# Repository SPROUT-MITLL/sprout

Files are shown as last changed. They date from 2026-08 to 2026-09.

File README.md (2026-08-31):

# SPROUT

Main repository for SPROUT: an open-source, open-hardware soft robot for search and rescue.

📖 **Full documentation, CAD, electronics, and software guides: [sprout-mitll.github.io/sprout](https://sprout-mitll.github.io/sprout/)**

## Repository layout

- [`SPROUT_Design/CAD`](SPROUT_Design/CAD) — SolidWorks/STEP mechanical design files
- [`SPROUT_Design/Code`](SPROUT_Design/Code) — Jetson bootstrap guide and the `sprout_ros` ROS 2 stack
- [`SPROUT_Design/Documentation`](SPROUT_Design/Documentation) — supporting photos and the raw BOM spreadsheet for the [Documentation](https://sprout-mitll.github.io/sprout/documentation/) section of the site
- [`SPROUT_Design/Electronics`](SPROUT_Design/Electronics) — custom Arduino shield KiCad project
- [`docs/`](docs) — source for the GitHub Pages documentation site above

## License

Released under the [MIT License](LICENSE).

## Distribution Statement

DISTRIBUTION STATEMENT A. Approved for public release. Distribution is unlimited.
This material is based upon work supported by the Department of the Air Force under Air Force Contract No. FA8702-15-D-0001 or FA8702-25-D-B002. Any opinions, findings, conclusions or recommendations expressed in this material are those of the author(s) and do not necessarily reflect the views of the Department of the Air Force.
© 2026 Massachusetts Institute of Technology.

Subject to FAR52.227-11 Patent Rights - Ownership by the contractor (May 2014)
Delivered to the U.S. Government with Unlimited Rights, as defined in DFARS Part 252.227-7013 or 7014 (Feb 2014). Notwithstanding any copyright notice, U.S. Government rights in this work are defined by DFARS 252.227-7013 or DFARS 252.227-7014 as detailed above. Use of this work other than as specifically authorized by the U.S. Government may violate any copyrights that exist in this work.

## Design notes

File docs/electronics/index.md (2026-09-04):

---
layout: default
title: Electronics
nav_order: 4
has_children: true
permalink: /electronics/
---

# Electronics
{: .no_toc }

Source: [`SPROUT_Design/Electronics`]({{ site.github_tree }}/SPROUT_Design/Electronics)
{: .label .label-green }

The `Electronics` directory contains the custom Arduino shield PCB that
interfaces the Arduino Uno Rev3 with the motor driver, QB3 pressure
regulators, solenoid valve, LCD screen, and the compute box's power rails (see
[Wiring]({{ site.baseurl }}/documentation/wiring.html) for the full pinout).

## Table of contents
{: .no_toc .text-delta }

- TOC
{:toc}

---

## Arduino shield

Source: [`Electronics/Arduino Shield`]({{ site.github_tree }}/SPROUT_Design/Electronics/Arduino%20Shield)
{: .label .label-green }

Designed in KiCad. The project targets an Arduino Uno Rev3 shield footprint
and breaks out the following interfaces referenced throughout the
[wiring guide]({{ site.baseurl }}/documentation/wiring.html):

- Motor driver power and control (`M_DRV_PWR`, `M_DRV_ARD`, `M_5V`)
- Solenoid valve output
- 15 V actuator/regulator rails (`M_15V`, `R_15V`)
- QB3 pressure regulator channels (Chamber, Actuator 1–3)
- I²C breakout for the LCD display

### 3D preview

{% assign step_url = site.github_raw | append: "/SPROUT_Design/Electronics/Arduino Shield/vine_robot_arduino_shield.step" %}
{% include step_viewer.html url=step_url name="Arduino shield" %}

<script type="module" src="{{ site.baseurl }}/assets/js/step-viewer.js"></script>

### Board layout

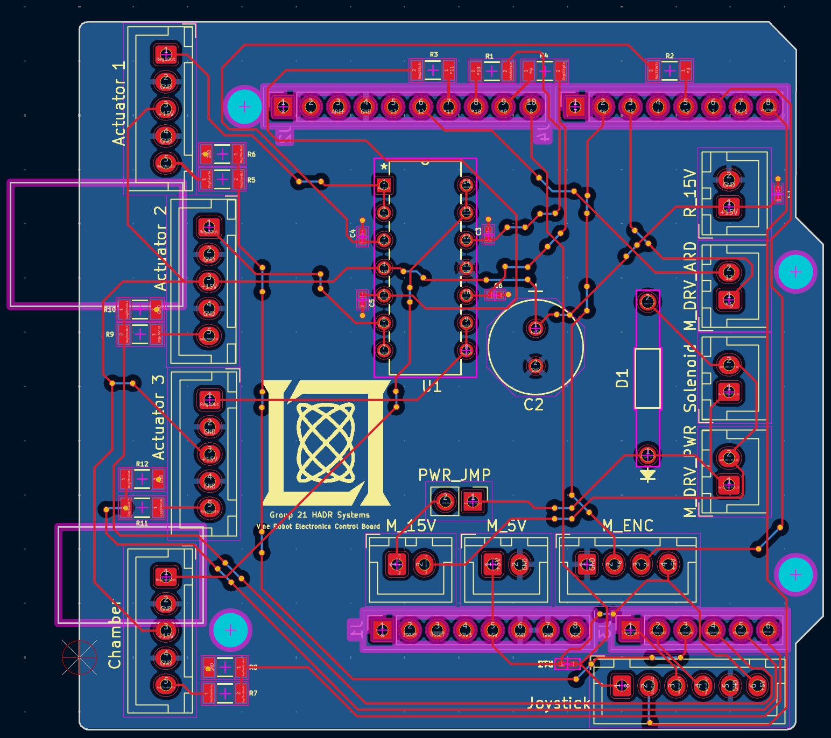
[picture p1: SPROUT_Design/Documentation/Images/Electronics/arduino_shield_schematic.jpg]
Arduino shield PCB layout


*Figure 1. PCB layout showing traces and connector pinouts for the actuator, solenoid, motor driver, power, encoder, and joystick headers referenced in the [wiring guide]({{ site.baseurl }}/documentation/wiring.html).*

| File | Description |
|---|---|
| [`vine_robot_arduino_shield.kicad_sch`]({{ site.github_blob }}/SPROUT_Design/Electronics/Arduino%20Shield/vine_robot_arduino_shield.kicad_sch) | KiCad schematic |
| [`vine_robot_arduino_shield.kicad_pcb`]({{ site.github_blob }}/SPROUT_Design/Electronics/Arduino%20Shield/vine_robot_arduino_shield.kicad_pcb) | KiCad PCB layout |
| [`vine_robot_arduino_shield.kicad_pro`]({{ site.github_blob }}/SPROUT_Design/Electronics/Arduino%20Shield/vine_robot_arduino_shield.kicad_pro) | KiCad project file |
| [`vine_robot_arduino_shield.step`]({{ site.github_blob }}/SPROUT_Design/Electronics/Arduino%20Shield/vine_robot_arduino_shield.step) | 3D STEP model of the assembled board |
| [`v2_gerbers_8_23_2/`]({{ site.github_tree }}/SPROUT_Design/Electronics/Arduino%20Shield/v2_gerbers_8_23_2) | Fabrication-ready Gerber/drill files (rev. 8/23, v2) |
| [`Arduino_MountingHole.pretty/`]({{ site.github_tree }}/SPROUT_Design/Electronics/Arduino%20Shield/Arduino_MountingHole.pretty) | Custom KiCad footprint library: standard Arduino mounting holes |
| [`Arduino_MountingHole_3.2mm.pretty/`]({{ site.github_tree }}/SPROUT_Design/Electronics/Arduino%20Shield/Arduino_MountingHole_3.2mm.pretty) | Custom KiCad footprint library: 3.2 mm mounting holes |

To fabricate a board, download the contents of the `v2_gerbers_8_23_2` folder (or
the corresponding `.zip`) and submit it directly to your PCB manufacturer of
choice.

To open and edit the design, clone the repository and open
`vine_robot_arduino_shield.kicad_pro` in [KiCad](https://www.kicad.org/) 7 or
later — the custom footprint libraries in this folder are referenced by the
project's local `fp-lib-table` and will resolve automatically.

## Related hardware

The shield is mounted alongside the Arduino Uno Rev3 in the compute box — see
[Assembly → Step 3]({{ site.baseurl }}/documentation/assembly.html#step-3-install-compute-hardware)
for installation and [Wiring]({{ site.baseurl }}/documentation/wiring.html) for the full
connector pinout. CAD for the shield's mechanical footprint and mounting is
included in [CAD → Compute Box]({{ site.baseurl }}/cad/new-compute-box.html).

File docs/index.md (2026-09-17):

---
title: Home
layout: home
nav_order: 1
permalink: /
---

{: .fs-9 }

<div style="position: relative; padding-bottom: 56.25%; height: 0; overflow: hidden; max-width: 100%; margin-bottom: 1.5rem;">
  <iframe src="https://www.youtube.com/embed/DaMCTH4qZTE" title="SPROUT overview video" style="position: absolute; top: 0; left: 0; width: 100%; height: 100%; border: 0;" allow="accelerometer; autoplay; clipboard-write; encrypted-media; gyroscope; picture-in-picture; web-share" allowfullscreen></iframe>
</div>

<i>An open-source, open-hardware soft robot platform for search and rescue and confined space operations.</i>
{: .fs-6 .fw-300 }

[Get started with Documentation]({{ site.baseurl }}/documentation/){: .btn .btn-primary .fs-5 .mb-4 .mb-md-0 .mr-2 }
[View the repository on GitHub](https://github.com/SPROUT-MITLL/sprout){: .btn .fs-5 .mb-4 .mb-md-0 }

---

## What is SPROUT?

SPROUT is a fully open-source, open-hardware soft robot built for search-and-rescue
applications. It pairs a pneumatically-actuated "vine robot" body with a
field-deployable compute box that handles onboard computation, power
regulation, actuator control, sensing, and networking.

Everything needed to build your own SPROUT — mechanical CAD, PCB designs, bills
of materials, assembly instructions, and the full software/ROS 2 stack — is
released here under the MIT license.

## Site Map

This site mirrors the folder structure of the [`SPROUT_Design`]({{ site.github_tree }}/SPROUT_Design) directory in the repository, so every page here has a matching source folder you can browse, clone, or download.

| Section | What's inside | Source folder |
|---|---|---|
| [Documentation]({{ site.baseurl }}/documentation/) | Bill of materials, enclosure prep, assembly, and wiring guides for the compute box | [`SPROUT_Design/Documentation`]({{ site.github_tree }}/SPROUT_Design/Documentation) (photos and BOM spreadsheet only — guides are authored directly on this site) |
| [CAD]({{ site.baseurl }}/cad/) | SolidWorks/STEP models for the compute box and robot base | [`SPROUT_Design/CAD`]({{ site.github_tree }}/SPROUT_Design/CAD) |
| [Electronics]({{ site.baseurl }}/electronics/) | Custom Arduino shield PCB (KiCad project, gerbers, schematics) | [`SPROUT_Design/Electronics`]({{ site.github_tree }}/SPROUT_Design/Electronics) |
| [Software]({{ site.baseurl }}/software/) | Jetson bootstrap guide and the `sprout_ros` ROS 2 stack | [`SPROUT_Design/Code`]({{ site.github_tree }}/SPROUT_Design/Code) |

## Getting Help

Have a question, run into an issue building your own SPROUT, or spot something
that needs fixing in the docs? [Open an issue on
GitHub](https://github.com/SPROUT-MITLL/sprout/issues) — it's the best way to
reach the team and helps other builders who run into the same thing.

## Citation

A paper describing SPROUT is available on [arXiv](https://arxiv.org/abs/2609.17781). If you use SPROUT in your research, please cite it using the entry below.

{: .note }

```bibtex
@misc{valdivia2026sprout,
      title={SPROUT: The Open-Source Soft Growing Robot for Search and Rescue}, 
      author={Antonio Alvarez Valdivia and Ciera McFarland and Robert Reeve and Ankush Dhawan and Chad Council and Megan Richardson and Margaret McGuinness and Nathaniel Hanson},
      year={2026},
      eprint={2609.17781},
      archivePrefix={arXiv},
      primaryClass={cs.RO},
      url={https://arxiv.org/abs/2609.17781}, 
}
```

## License

SPROUT is released under the [MIT License]({{ site.github_blob }}/LICENSE).

---

## Team

<style>
  .team-grid {
    display: flex;
    flex-wrap: wrap;
    justify-content: center;
    gap: 2rem;
    margin: 1.5rem 0 2rem;
  }
  .team-member {
    width: 140px;
    text-align: center;
  }
  .team-member img {
    width: 120px;
    height: 120px;
    object-fit: cover;
    border-radius: 50%;
    display: block;
    margin: 0 auto 0.6rem;
    box-shadow: 0 1px 4px rgba(0, 0, 0, 0.2);
    background-color: #eaf5ec;
  }
  .team-member .team-name {
    font-weight: 600;
    font-size: 0.95rem;
  }
  .team-member .team-role {
    font-size: 0.8rem;
    color: #5c5962;
  }
</style>

<!-- Add one .team-member block per collaborator; headshots live in assets/images/team/ -->
<div class="team-grid">
  <div class="team-member">
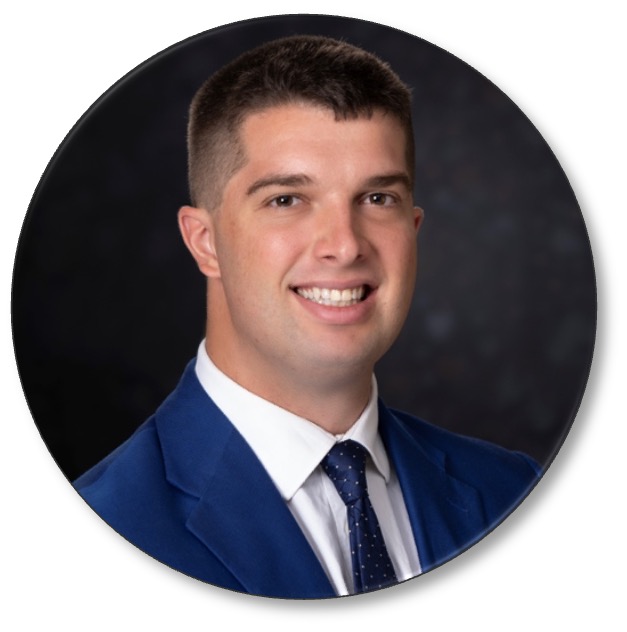
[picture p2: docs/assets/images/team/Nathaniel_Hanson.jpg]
Nathaniel Hanson
    
    <div class="team-name">Nathaniel Hanson</div>
    <div class="team-role">Principal Investigator, MIT Lincoln Laboratory</div>
  </div>
  <div class="team-member">
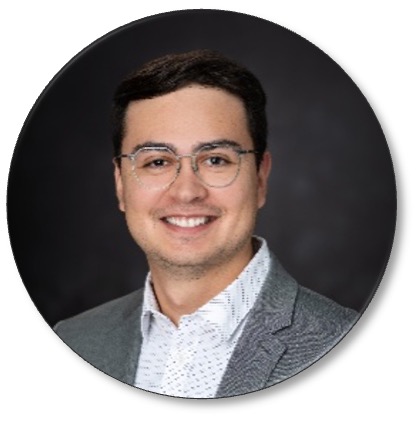
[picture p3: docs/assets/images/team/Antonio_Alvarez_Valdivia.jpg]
Antonio Alvarez Valdivia
    
    <div class="team-name">Antonio Alvarez Valdivia</div>
    <div class="team-role">MIT Lincoln Laboratory</div>
  </div>
  <div class="team-member">
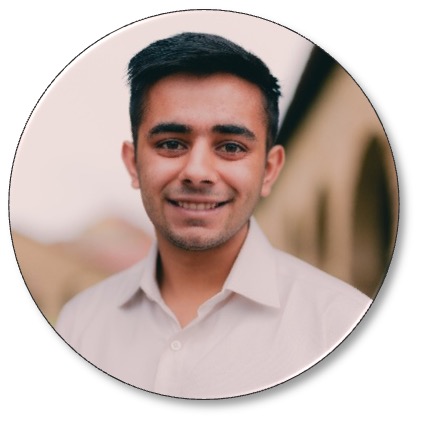
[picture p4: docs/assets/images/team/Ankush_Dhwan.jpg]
Ankush Dhwan
    
    <div class="team-name">Ankush Dhwan</div>
    <div class="team-role">MIT Lincoln Laboratory</div>
  </div>
  <div class="team-member">
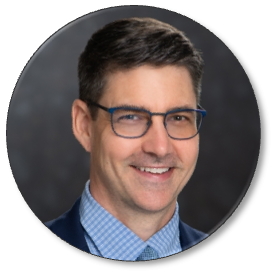
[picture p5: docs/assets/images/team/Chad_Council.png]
Chad Council
    
    <div class="team-name">Chad Council</div>
    <div class="team-role">MIT Lincoln Laboratory</div>
  </div>
  <div class="team-member">
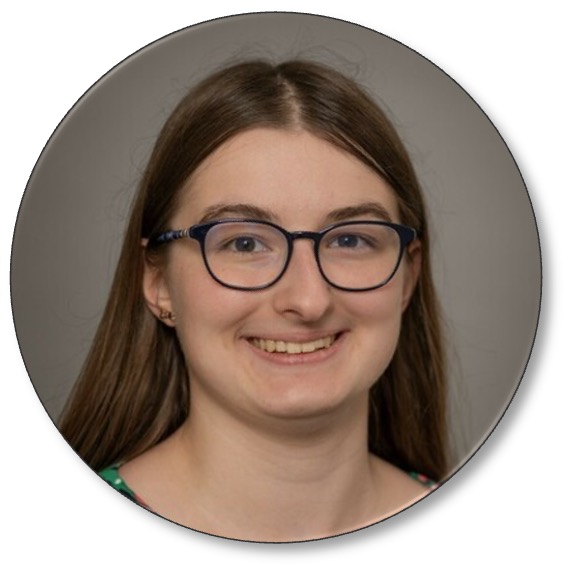
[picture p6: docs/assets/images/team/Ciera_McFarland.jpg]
Ciera McFarland
    
    <div class="team-name">Ciera McFarland</div>
    <div class="team-role">University of Notre Dame</div>
  </div>
  <div class="team-member">
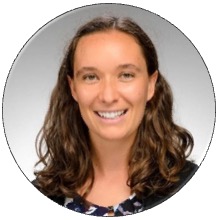
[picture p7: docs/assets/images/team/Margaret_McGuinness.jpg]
Margaret McGuinness
    
    <div class="team-name">Margaret McGuinness</div>
    <div class="team-role">University of Notre Dame</div>
  </div>
  <div class="team-member">
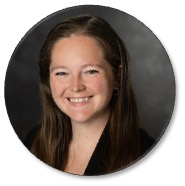
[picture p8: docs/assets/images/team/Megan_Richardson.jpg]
Megan Richardson
    
    <div class="team-name">Megan Richardson</div>
    <div class="team-role">MIT Lincoln Laboratory</div>
  </div>
  <div class="team-member">
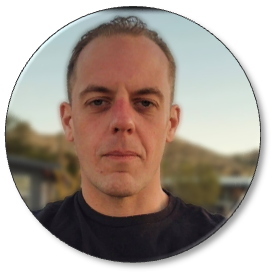
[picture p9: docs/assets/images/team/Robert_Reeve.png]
Robert Reeve
    
    <div class="team-name">Robert Reeve</div>
    <div class="team-role">MIT Lincoln Laboratory</div>
  </div>
</div>

<div style="display: flex; align-items: center; justify-content: center; gap: 3rem; flex-wrap: wrap; margin: 2rem 0 1rem;">
  <a href="https://www.nd.edu" target="_blank" rel="noopener">University of Notre Dame</a>
  <a href="https://www.ll.mit.edu" target="_blank" rel="noopener">MIT Lincoln Laboratory</a>
</div>
<p style="text-align: center; font-size: 0.85rem; color: #5c5962; margin-bottom: 2rem;">A joint project of the University of Notre Dame and MIT Lincoln Laboratory.</p>

## Distribution Statement

DISTRIBUTION STATEMENT A. Approved for public release. Distribution is unlimited.
This material is based upon work supported by the Department of the Air Force under Air Force Contract No. FA8702-15-D-0001 or FA8702-25-D-B002. Any opinions, findings, conclusions or recommendations expressed in this material are those of the author(s) and do not necessarily reflect the views of the Department of the Air Force.
© 2026 Massachusetts Institute of Technology.

Subject to FAR52.227-11 Patent Rights - Ownership by the contractor (May 2014)
Delivered to the U.S. Government with Unlimited Rights, as defined in DFARS Part 252.227-7013 or 7014 (Feb 2014). Notwithstanding any copyright notice, U.S. Government rights in this work are defined by DFARS 252.227-7013 or DFARS 252.227-7014 as detailed above. Use of this work other than as specifically authorized by the U.S. Government may violate any copyrights that exist in this work.

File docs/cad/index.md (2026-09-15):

---
layout: default
title: CAD
nav_order: 3
has_children: true
permalink: /cad/
---

# CAD
{: .no_toc }

Source: [`SPROUT_Design/CAD`]({{ site.github_tree }}/SPROUT_Design/CAD)
{: .label .label-green }

Mechanical design files for SPROUT, authored in SolidWorks with STEP exports
for interchange with other CAD tools. Individual part files are binary and
are not rendered inline — follow the links on the pages below to view file
details on GitHub or clone the repository to open them locally.

| Folder | Description |
|---|---|
| [Compute Box]({{ site.baseurl }}/cad/new-compute-box.html) | Full compute box design: enclosure mounts, electropneumatic hardware, power electronics, connectors, and robot-base interface |
| [Base CAD]({{ site.baseurl }}/cad/new-base-cad.html) | Robot base design: the motorized reel mechanism that houses, drives, and everts the vine body |

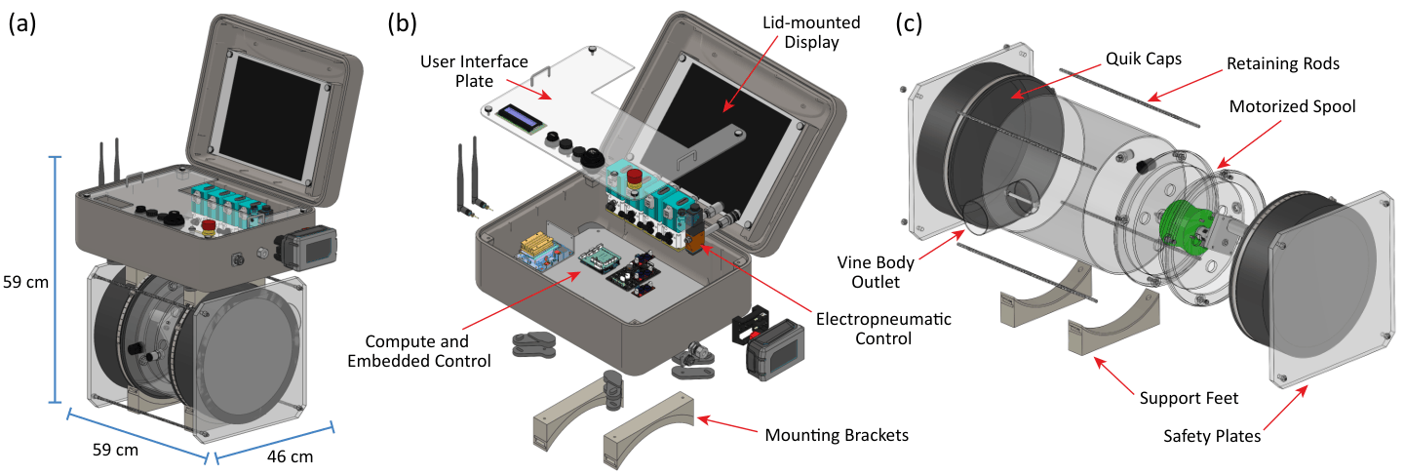
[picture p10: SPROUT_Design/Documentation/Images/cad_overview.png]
CAD Overview


*(a) Assembled SPROUT platform and overall dimensions. (b) Exploded view of the compute box. (c) Exploded view of the vine base.*

## 3D preview

The full SPROUT assembly (compute box + robot base) can be previewed directly in the browser.

{% assign step_url = site.github_raw | append: "/SPROUT_Design/CAD/SPROUT_assembly_exterior.stl" %}
{% include step_viewer.html url=step_url name="SPROUT assembly" %}

<script type="module" src="{{ site.baseurl }}/assets/js/step-viewer.js"></script>

## Working with these files

- **SolidWorks** (`.SLDPRT`, `.SLDASM`, `.SLDDRW`) — open directly in SolidWorks. Top-level assemblies are the `.SLDASM` files.
- **STEP** (`.STEP`/`.step`) — neutral format importable into any major CAD package (SolidWorks, Fusion 360, OnShape, FreeCAD, etc.).
- Clone the repository to get all files at once:

```bash
git clone https://github.com/SPROUT-MITLL/sprout.git
```

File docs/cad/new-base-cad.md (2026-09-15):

---
layout: default
title: Base CAD
parent: CAD
nav_order: 2
---

# Base CAD
{: .no_toc }

Source: [`SPROUT_Design/CAD/Solidworks/sprout_base`]({{ site.github_tree }}/SPROUT_Design/CAD/Solidworks/sprout_base)
{: .label .label-green }

Mechanical design for the robot base — the motorized reel mechanism that
houses, drives, and everts the [vine body]({{ site.baseurl }}/documentation/vine-construction.html)
— following the [vinerobots.org](https://www.vinerobots.org/) base design,
with modifications noted in
[Assembly → Step 8]({{ site.baseurl }}/documentation/assembly.html#step-8-assembly-with-robot-base).
See [Compute Box]({{ site.baseurl }}/cad/new-compute-box.html) for the compute box that mounts
to this base.

## Table of contents
{: .no_toc .text-delta }

- TOC
{:toc}

---

## Subassemblies

| File | Description |
|---|---|
| [`Base_assembly.SLDASM`]({{ site.github_blob }}/SPROUT_Design/CAD/Solidworks/sprout_base/Base_assembly.SLDASM) | Top-level base assembly |
| [`mounting_plate_subassembly.SLDASM`]({{ site.github_blob }}/SPROUT_Design/CAD/Solidworks/sprout_base/mounting_plate_subassembly.SLDASM) | Motor/bearing mounting plate subassembly |
| [`spool_subassembly.SLDASM`]({{ site.github_blob }}/SPROUT_Design/CAD/Solidworks/sprout_base/spool_subassembly.SLDASM) | Reel/spool subassembly |
| [`outlet_subassembly.SLDASM`]({{ site.github_blob }}/SPROUT_Design/CAD/Solidworks/sprout_base/outlet_subassembly.SLDASM) | Vine outlet subassembly |

## Reel / spool mechanism

| File | Description |
|---|---|
| [`SpoolBig.SLDPRT`]({{ site.github_blob }}/SPROUT_Design/CAD/Solidworks/sprout_base/SpoolBig.SLDPRT) / [`.STL`]({{ site.github_blob }}/SPROUT_Design/CAD/Solidworks/sprout_base/SpoolBig.STL) | Main reel/spool |
| [`SpoolGuideLarge.SLDPRT`]({{ site.github_blob }}/SPROUT_Design/CAD/Solidworks/sprout_base/SpoolGuideLarge.SLDPRT) | Spool guide |
| [`HexHolder.SLDPRT`]({{ site.github_blob }}/SPROUT_Design/CAD/Solidworks/sprout_base/HexHolder.SLDPRT) | Hex shaft-to-spool holder |
| [`BearingHolder.SLDPRT`]({{ site.github_blob }}/SPROUT_Design/CAD/Solidworks/sprout_base/BearingHolder.SLDPRT) | Bearing holder |
| [`BearingPlateLarge.SLDPRT`]({{ site.github_blob }}/SPROUT_Design/CAD/Solidworks/sprout_base/BearingPlateLarge.SLDPRT) | Bearing mounting plate |
| [`MotorPlateLarge.SLDPRT`]({{ site.github_blob }}/SPROUT_Design/CAD/Solidworks/sprout_base/MotorPlateLarge.SLDPRT) | Motor mounting plate |
| [`Holder Plate Large.SLDPRT`]({{ site.github_blob }}/SPROUT_Design/CAD/Solidworks/sprout_base/Holder%20Plate%20Large.SLDPRT) | Reel holder plate |
| [`sprout_feet.SLDPRT`]({{ site.github_blob }}/SPROUT_Design/CAD/Solidworks/sprout_base/sprout_feet.SLDPRT) | Base feet |

## Drive train & shaft components

| File | Description |
|---|---|
| [`6409K27_Compact Square-Face DC Gearmotor.SLDPRT`]({{ site.github_blob }}/SPROUT_Design/CAD/Solidworks/sprout_base/6409K27_Compact%20Square-Face%20DC%20Gearmotor.SLDPRT) | Drive gearmotor |
| [`1314-0016-0250 assembly.STEP`]({{ site.github_blob }}/SPROUT_Design/CAD/Solidworks/sprout_base/1314-0016-0250%20assembly.STEP) | Vendor gearmotor assembly reference (STEP export) |
| [`6408K111_Flexible Shaft Coupling Iron Hub.SLDPRT`]({{ site.github_blob }}/SPROUT_Design/CAD/Solidworks/sprout_base/6408K111_Flexible%20Shaft%20Coupling%20Iron%20Hub.SLDPRT) | Flexible shaft coupling hub |
| [`6408K84_18000 rpm Buna-N Rubber Spider for 1-5-64 OD Flexible Shaft Coupling Iron Hub.SLDPRT`]({{ site.github_blob }}/SPROUT_Design/CAD/Solidworks/sprout_base/6408K84_18000%20rpm%20Buna-N%20Rubber%20Spider%20for%201-5-64%20OD%20Flexible%20Shaft%20Coupling%20Iron%20Hub.SLDPRT) | Rubber spider insert for the shaft coupling |
| [`6432K12_Set Screw Shaft Collar.SLDPRT`]({{ site.github_blob }}/SPROUT_Design/CAD/Solidworks/sprout_base/6432K12_Set%20Screw%20Shaft%20Collar.SLDPRT) | Set screw shaft collar |
| [`1870K1_Easy-Access Flange-Mounted Shaft Support.SLDPRT`]({{ site.github_blob }}/SPROUT_Design/CAD/Solidworks/sprout_base/1870K1_Easy-Access%20Flange-Mounted%20Shaft%20Support.SLDPRT) | Flange-mounted shaft support |
| [`1886K1_Rotary Shaft.SLDPRT`]({{ site.github_blob }}/SPROUT_Design/CAD/Solidworks/sprout_base/1886K1_Rotary%20Shaft.SLDPRT) | Rotary shaft |
| [`8632T139_D-Profile Rotary Shaft.SLDPRT`]({{ site.github_blob }}/SPROUT_Design/CAD/Solidworks/sprout_base/8632T139_D-Profile%20Rotary%20Shaft.SLDPRT) | D-profile rotary shaft |
| [`57155K336_Stainless Steel Ball Bearing.SLDPRT`]({{ site.github_blob }}/SPROUT_Design/CAD/Solidworks/sprout_base/57155K336_Stainless%20Steel%20Ball%20Bearing.SLDPRT) | Stainless steel ball bearing |
| [`60355K151_Ball Bearing.SLDPRT`]({{ site.github_blob }}/SPROUT_Design/CAD/Solidworks/sprout_base/60355K151_Ball%20Bearing.SLDPRT) | Ball bearing |

## Tube & housing

| File | Description |
|---|---|
| [`84865K315_Clear Scratch- and UV-Resistant Cast Acrylic Tube.SLDPRT`]({{ site.github_blob }}/SPROUT_Design/CAD/Solidworks/sprout_base/84865K315_Clear%20Scratch-%20and%20UV-Resistant%20Cast%20Acrylic%20Tube.SLDPRT) | Clear acrylic housing tube |
| [`8585K391_Impact-Resistant Polycarbonate Round Tube.SLDPRT`]({{ site.github_blob }}/SPROUT_Design/CAD/Solidworks/sprout_base/8585K391_Impact-Resistant%20Polycarbonate%20Round%20Tube.SLDPRT) | Polycarbonate housing tube |

## Pneumatic & electrical fittings

| File | Description |
|---|---|
| [`4511K115_Low-Pressure Connector for Drain, Waste and Vent.SLDPRT`]({{ site.github_blob }}/SPROUT_Design/CAD/Solidworks/sprout_base/4511K115_Low-Pressure%20Connector%20for%20Drain,%20Waste%20and%20Vent.SLDPRT) | Low-pressure vent connector |
| [`50785K142_High-Pressure Brass Pipe Fitting.SLDPRT`]({{ site.github_blob }}/SPROUT_Design/CAD/Solidworks/sprout_base/50785K142_High-Pressure%20Brass%20Pipe%20Fitting.SLDPRT) | High-pressure brass pipe fitting |
| [`5779K119_Push-to-Connect Tube Fitting for Air.SLDPRT`]({{ site.github_blob }}/SPROUT_Design/CAD/Solidworks/sprout_base/5779K119_Push-to-Connect%20Tube%20Fitting%20for%20Air.SLDPRT) | Push-to-connect fitting |
| [`69915K54_Plastic Submersible Cord Grip (1).SLDPRT`]({{ site.github_blob }}/SPROUT_Design/CAD/Solidworks/sprout_base/69915K54_Plastic%20Submersible%20Cord%20Grip%20(1).SLDPRT) | Cable gland for wiring pass-through |

## Fasteners & hardware

| File | Description |
|---|---|
| [`90480A195_Low-Strength Steel Hex Nut.SLDPRT`]({{ site.github_blob }}/SPROUT_Design/CAD/Solidworks/sprout_base/90480A195_Low-Strength%20Steel%20Hex%20Nut.SLDPRT) | Hex nut |
| [`95462A029_Medium-Strength Steel Hex Nut.SLDPRT`]({{ site.github_blob }}/SPROUT_Design/CAD/Solidworks/sprout_base/95462A029_Medium-Strength%20Steel%20Hex%20Nut.SLDPRT) | Hex nut |
| [`91290A121_Alloy Steel Socket Head Screw.SLDPRT`]({{ site.github_blob }}/SPROUT_Design/CAD/Solidworks/sprout_base/91290A121_Alloy%20Steel%20Socket%20Head%20Screw.SLDPRT) | Socket head screw |
| [`96006A709_Black Oxide 18-8 Stainless Steel Socket Head Screw.SLDPRT`]({{ site.github_blob }}/SPROUT_Design/CAD/Solidworks/sprout_base/96006A709_Black%20Oxide%2018-8%20Stainless%20Steel%20Socket%20Head%20Screw.SLDPRT) | Socket head screw |
| [`94180A331_Tapered Heat-Set Inserts for Plastic.SLDPRT`]({{ site.github_blob }}/SPROUT_Design/CAD/Solidworks/sprout_base/94180A331_Tapered%20Heat-Set%20Inserts%20for%20Plastic.SLDPRT) | Heat-set threaded insert |

See the [Bill of Materials]({{ site.baseurl }}/documentation/bom.html) for the matching McMaster-Carr/vendor part numbers.

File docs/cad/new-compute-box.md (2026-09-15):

---
layout: default
title: Compute Box
parent: CAD
nav_order: 1
---

# Compute Box CAD
{: .no_toc }

Source: [`SPROUT_Design/CAD/Solidworks/compute_box`]({{ site.github_tree }}/SPROUT_Design/CAD/Solidworks/compute_box)
{: .label .label-green }

Full mechanical design for the compute box described in
[Documentation]({{ site.baseurl }}/documentation/): enclosure mounts, electropneumatic hardware,
power electronics, connectors, and the robot-base interface. See
[Assembly]({{ site.baseurl }}/documentation/assembly.html) and
[Enclosure]({{ site.baseurl }}/documentation/enclosure.html) for how these parts go together.

## Table of contents
{: .no_toc .text-delta }

- TOC
{:toc}

---

## Top-level assemblies

| File | Description |
|---|---|
| [`compute_box.SLDASM`]({{ site.github_blob }}/SPROUT_Design/CAD/Solidworks/compute_box/compute_box.SLDASM) / [`compute_box_assembly.SLDASM`]({{ site.github_blob }}/SPROUT_Design/CAD/Solidworks/compute_box/compute_box_assembly.SLDASM) | Top-level compute box assembly |
| [`case.SLDASM`]({{ site.github_blob }}/SPROUT_Design/CAD/Solidworks/compute_box/case.SLDASM) / [`case_assembly.SLDASM`]({{ site.github_blob }}/SPROUT_Design/CAD/Solidworks/compute_box/case_assembly.SLDASM) | Enclosure case assembly |
| [`jetson_subassembly.SLDASM`]({{ site.github_blob }}/SPROUT_Design/CAD/Solidworks/compute_box/jetson_subassembly.SLDASM) | Jetson computer + mounting housing subassembly |
| [`feet_assembly.SLDASM`]({{ site.github_blob }}/SPROUT_Design/CAD/Solidworks/compute_box/feet_assembly.SLDASM) | External robot mounting foot assembly (see [Enclosure]({{ site.baseurl }}/documentation/enclosure.html#external-robot-mounting-system)) |
| [`EMERGENCY STOP SWITCH.SLDASM`]({{ site.github_blob }}/SPROUT_Design/CAD/Solidworks/compute_box/EMERGENCY%20STOP%20SWITCH.SLDASM) | E-stop switch assembly |
| [`1_8 NPT - 1_4 Inch Push to Connect Elbow Fitting.SLDASM`]({{ site.github_blob }}/SPROUT_Design/CAD/Solidworks/compute_box/1_8%20NPT%20-%201_4%20Inch%20Push%20to%20Connect%20Elbow%20Fitting.SLDASM) | Pneumatic elbow fitting assembly |
| [`UA-006.SLDASM`]({{ site.github_blob }}/SPROUT_Design/CAD/Solidworks/compute_box/UA-006.SLDASM) | Vendor sub-assembly |

## Enclosure & case

| File | Description |
|---|---|
| [`case.SLDPRT`]({{ site.github_blob }}/SPROUT_Design/CAD/Solidworks/compute_box/case.SLDPRT) | Enclosure case body |
| [`bottom_panel.SLDPRT`]({{ site.github_blob }}/SPROUT_Design/CAD/Solidworks/compute_box/bottom_panel.SLDPRT) | Enclosure bottom mounting panel |
| [`top_interface.SLDPRT`]({{ site.github_blob }}/SPROUT_Design/CAD/Solidworks/compute_box/top_interface.SLDPRT) | Top interface panel |
| [`acrylic_top.SLDPRT`]({{ site.github_blob }}/SPROUT_Design/CAD/Solidworks/compute_box/acrylic_top.SLDPRT) / [`.SLDDRW`]({{ site.github_blob }}/SPROUT_Design/CAD/Solidworks/compute_box/acrylic_top.SLDDRW) / [`.DXF`]({{ site.github_blob }}/SPROUT_Design/CAD/Solidworks/compute_box/acrylic_top.DXF) / [`.pdf`]({{ site.github_blob }}/SPROUT_Design/CAD/Solidworks/compute_box/acrylic_top.pdf) | Acrylic top panel model, drawing, cut file, and print-ready PDF |
| [`CASE_930_R1_Btm_INNER_SURFACE.SLDPRT`]({{ site.github_blob }}/SPROUT_Design/CAD/Solidworks/compute_box/CASE_930_R1_Btm_INNER_SURFACE.SLDPRT) | NANUK 930 case bottom inner-surface reference (manufacturer geometry) |
| [`CASE_930_R1_Btm_INNER_SURFACE_hole_drawing.SLDDRW`]({{ site.github_blob }}/SPROUT_Design/CAD/Solidworks/compute_box/CASE_930_R1_Btm_INNER_SURFACE_hole_drawing.SLDDRW) / [`.pdf`]({{ site.github_blob }}/SPROUT_Design/CAD/Solidworks/compute_box/CASE_930_R1_Btm_INNER_SURFACE_hole_drawing.pdf) | Mounting hole drawing for the case bottom |
| [`CASE_930_R1_Top_INNER_SURFACE.SLDPRT`]({{ site.github_blob }}/SPROUT_Design/CAD/Solidworks/compute_box/CASE_930_R1_Top_INNER_SURFACE.SLDPRT) | NANUK 930 case top inner-surface reference (manufacturer geometry) |
| [`930_R1_INNER_SURFACE_STEP/`]({{ site.github_tree }}/SPROUT_Design/CAD/Solidworks/compute_box/930_R1_INNER_SURFACE_STEP) / [`.zip`]({{ site.github_blob }}/SPROUT_Design/CAD/Solidworks/compute_box/930_R1_INNER_SURFACE_STEP.zip) | Manufacturer-provided NANUK 930 inner-surface STEP files (top + bottom), used as the reference geometry for the mounting brackets (see [Enclosure]({{ site.baseurl }}/documentation/enclosure.html)) |

## Screen, plate & regulator mounting

| File | Description |
|---|---|
| [`screen.SLDPRT`]({{ site.github_blob }}/SPROUT_Design/CAD/Solidworks/compute_box/screen.SLDPRT) | Display panel reference model |
| [`screen_holder.SLDPRT`]({{ site.github_blob }}/SPROUT_Design/CAD/Solidworks/compute_box/screen_holder.SLDPRT) / [`.STL`]({{ site.github_blob }}/SPROUT_Design/CAD/Solidworks/compute_box/screen_holder.STL) | Display mounting bracket |
| [`screen_holder_extended.SLDPRT`]({{ site.github_blob }}/SPROUT_Design/CAD/Solidworks/compute_box/screen_holder_extended.SLDPRT) / [`.STL`]({{ site.github_blob }}/SPROUT_Design/CAD/Solidworks/compute_box/screen_holder_extended.STL) | Extended display mounting bracket |
| [`screen_and_plate_holders.3mf`]({{ site.github_blob }}/SPROUT_Design/CAD/Solidworks/compute_box/screen_and_plate_holders.3mf) | Sliced 3D-print file for the screen and plate holder brackets |
| [`plate_corner_holder.SLDPRT`]({{ site.github_blob }}/SPROUT_Design/CAD/Solidworks/compute_box/plate_corner_holder.SLDPRT) / [`.STL`]({{ site.github_blob }}/SPROUT_Design/CAD/Solidworks/compute_box/plate_corner_holder.STL) | Corner mounting bracket for the interior mounting plate |
| [`plate_interface.SLDPRT`]({{ site.github_blob }}/SPROUT_Design/CAD/Solidworks/compute_box/plate_interface.SLDPRT) / [`.STL`]({{ site.github_blob }}/SPROUT_Design/CAD/Solidworks/compute_box/plate_interface.STL) | Interior mounting plate interface |
| [`regulator_cover.SLDPRT`]({{ site.github_blob }}/SPROUT_Design/CAD/Solidworks/compute_box/regulator_cover.SLDPRT) / [`.STL`]({{ site.github_blob }}/SPROUT_Design/CAD/Solidworks/compute_box/regulator_cover.STL) / [`.3mf`]({{ site.github_blob }}/SPROUT_Design/CAD/Solidworks/compute_box/regulator_cover.3mf) | 3D-printed cover for the QB3 pressure regulators |

## Feet & robot mounting

| File | Description |
|---|---|
| [`feet_part_1.SLDPRT`]({{ site.github_blob }}/SPROUT_Design/CAD/Solidworks/compute_box/feet_part_1.SLDPRT), [`feet_part_2.SLDPRT`]({{ site.github_blob }}/SPROUT_Design/CAD/Solidworks/compute_box/feet_part_2.SLDPRT) | Curved support foot components (see [Enclosure]({{ site.baseurl }}/documentation/enclosure.html#external-robot-mounting-system)) |
| [`feet_rail_1.SLDPRT`]({{ site.github_blob }}/SPROUT_Design/CAD/Solidworks/compute_box/feet_rail_1.SLDPRT) | Mounting foot rail |
| [`feet_rail.SLDPRT`]({{ site.github_blob }}/SPROUT_Design/CAD/Solidworks/compute_box/feet_rail.SLDPRT) / [`.STL`]({{ site.github_blob }}/SPROUT_Design/CAD/Solidworks/compute_box/feet_rail.STL) | Mounting foot rail (current revision) |
| [`feet_rail_simplified.SLDPRT`]({{ site.github_blob }}/SPROUT_Design/CAD/Solidworks/compute_box/feet_rail_simplified.SLDPRT) / [`.STL`]({{ site.github_blob }}/SPROUT_Design/CAD/Solidworks/compute_box/feet_rail_simplified.STL) / [`_R.STL`]({{ site.github_blob }}/SPROUT_Design/CAD/Solidworks/compute_box/feet_rail_simplified_R.STL) | Simplified foot rail for 3D printing (left/right) |
| [`base_bottom_insert_left.SLDPRT`]({{ site.github_blob }}/SPROUT_Design/CAD/Solidworks/compute_box/base_bottom_insert_left.SLDPRT) / [`.STL`]({{ site.github_blob }}/SPROUT_Design/CAD/Solidworks/compute_box/base_bottom_insert_left.STL) | Base bottom insert (left) |
| [`base_bottom_insert_simplified.SLDPRT`]({{ site.github_blob }}/SPROUT_Design/CAD/Solidworks/compute_box/base_bottom_insert_simplified.SLDPRT) / [`.STL`]({{ site.github_blob }}/SPROUT_Design/CAD/Solidworks/compute_box/base_bottom_insert_simplified.STL) / [`_R.STL`]({{ site.github_blob }}/SPROUT_Design/CAD/Solidworks/compute_box/base_bottom_insert_simplified_R.STL) | Simplified base bottom insert for 3D printing (left/right) |

## Compute & electronics mounting

| File | Description |
|---|---|
| [`jetson_base.SLDPRT`]({{ site.github_blob }}/SPROUT_Design/CAD/Solidworks/compute_box/jetson_base.SLDPRT) / [`.STL`]({{ site.github_blob }}/SPROUT_Design/CAD/Solidworks/compute_box/jetson_base.STL) | 3D-printed Jetson mounting base |
| [`jetson_computer.SLDPRT`]({{ site.github_blob }}/SPROUT_Design/CAD/Solidworks/compute_box/jetson_computer.SLDPRT) | NVIDIA Jetson reference model |
| [`arduino uno.SLDPRT`]({{ site.github_blob }}/SPROUT_Design/CAD/Solidworks/compute_box/arduino%20uno.SLDPRT) | Arduino Uno Rev3 reference model |
| [`vine_robot_arduino_shield.SLDPRT`]({{ site.github_blob }}/SPROUT_Design/CAD/Solidworks/compute_box/vine_robot_arduino_shield.SLDPRT) / [`.step`]({{ site.github_blob }}/SPROUT_Design/CAD/Solidworks/compute_box/vine_robot_arduino_shield.step) | Custom Arduino shield (see [Electronics]({{ site.baseurl }}/electronics/)) |
| [`MDDS10.SLDPRT`]({{ site.github_blob }}/SPROUT_Design/CAD/Solidworks/compute_box/MDDS10.SLDPRT) | Cytron MDD10A dual-channel motor driver |
| [`xl6009_DCDC_BoostBuck.SLDPRT`]({{ site.github_blob }}/SPROUT_Design/CAD/Solidworks/compute_box/xl6009_DCDC_BoostBuck.SLDPRT) / [`.step`]({{ site.github_blob }}/SPROUT_Design/CAD/Solidworks/compute_box/xl6009_DCDC_BoostBuck.step) | DC-DC buck/boost converter module |
| [`QB3-3D.SLDPRT`]({{ site.github_blob }}/SPROUT_Design/CAD/Solidworks/compute_box/QB3-3D.SLDPRT) / [`.STEP`]({{ site.github_blob }}/SPROUT_Design/CAD/Solidworks/compute_box/QB3-3D.STEP) | ProportionAir QB3 pressure regulator |
| [`3V210-08NC SOLENOID VALVE.SLDPRT`]({{ site.github_blob }}/SPROUT_Design/CAD/Solidworks/compute_box/3V210-08NC%20SOLENOID%20VALVE.SLDPRT) | 3/2 NC solenoid valve |
| [`M18 Battery 8Ah.SLDPRT`]({{ site.github_blob }}/SPROUT_Design/CAD/Solidworks/compute_box/M18%20Battery%208Ah.SLDPRT) | M18 8Ah battery reference model |
| [`M18 battery mount.SLDPRT`]({{ site.github_blob }}/SPROUT_Design/CAD/Solidworks/compute_box/M18%20battery%20mount.SLDPRT) | Custom M18 battery mounting bracket |
| [`fiber_interface_PCB.SLDPRT`]({{ site.github_blob }}/SPROUT_Design/CAD/Solidworks/compute_box/fiber_interface_PCB.SLDPRT) | Reference model for the fiber/comms interface PCB |
| [`small_emergency_button.SLDPRT`]({{ site.github_blob }}/SPROUT_Design/CAD/Solidworks/compute_box/small_emergency_button.SLDPRT) | Small panel-mount E-stop button variant |

## Connectors, switches & fittings

| File | Description |
|---|---|
| [`1860N13_Wet-Location HDMI Connector.SLDPRT`]({{ site.github_blob }}/SPROUT_Design/CAD/Solidworks/compute_box/1860N13_Wet-Location%20HDMI%20Connector.SLDPRT) | Panel-mount HDMI connector |
| [`3216K56_Harsh Environment Mini Signal Power Connector.SLDPRT`]({{ site.github_blob }}/SPROUT_Design/CAD/Solidworks/compute_box/3216K56_Harsh%20Environment%20Mini%20Signal%20Power%20Connector.SLDPRT) | Sealed signal/power connector |
| [`5697T29_Wet-Location Data Connector.SLDPRT`]({{ site.github_blob }}/SPROUT_Design/CAD/Solidworks/compute_box/5697T29_Wet-Location%20Data%20Connector.SLDPRT) | Panel-mount Ethernet/data connector |
| [`8903T45_Mil. Spec. Signal-Power Connector.SLDPRT`]({{ site.github_blob }}/SPROUT_Design/CAD/Solidworks/compute_box/8903T45_Mil.%20Spec.%20Signal-Power%20Connector.SLDPRT) | Mil-spec signal/power connector |
| [`CNLINKO YU-USB.SLDPRT`]({{ site.github_blob }}/SPROUT_Design/CAD/Solidworks/compute_box/CNLINKO%20YU-USB.SLDPRT) | Panel-mount USB connector |
| [`EMERGENCY STOP DOME.SLDPRT`]({{ site.github_blob }}/SPROUT_Design/CAD/Solidworks/compute_box/EMERGENCY%20STOP%20DOME.SLDPRT), [`EMERGENCY STOP SWITCH.SLDPRT`]({{ site.github_blob }}/SPROUT_Design/CAD/Solidworks/compute_box/EMERGENCY%20STOP%20SWITCH.SLDPRT), [`EMERGENCY STOP YELLOW  PLATE.SLDPRT`]({{ site.github_blob }}/SPROUT_Design/CAD/Solidworks/compute_box/EMERGENCY%20STOP%20YELLOW%20%20PLATE.SLDPRT) | E-stop mushroom dome, switch body, and mounting plate |
| [`Push button 12mm.SLDPRT`]({{ site.github_blob }}/SPROUT_Design/CAD/Solidworks/compute_box/Push%20button%2012mm.SLDPRT) | 12 mm panel push button |
| [`Antenna_assembly v4.SLDPRT`]({{ site.github_blob }}/SPROUT_Design/CAD/Solidworks/compute_box/Antenna_assembly%20v4.SLDPRT) | WiFi/wireless NIC antenna assembly |
| [`1568A64_Threaded-Hole Round Pull Handle.SLDPRT`]({{ site.github_blob }}/SPROUT_Design/CAD/Solidworks/compute_box/1568A64_Threaded-Hole%20Round%20Pull%20Handle.SLDPRT) | Case pull handle |
| [`96016A237_Plastic-Head Thumb Screws.SLDPRT`]({{ site.github_blob }}/SPROUT_Design/CAD/Solidworks/compute_box/96016A237_Plastic-Head%20Thumb%20Screws.SLDPRT) | Thumb screws for tool-less panel access |
| [`92000A318_Passivated 18-8 Stainless Steel Pan Head Phillips Screws.SLDPRT`]({{ site.github_blob }}/SPROUT_Design/CAD/Solidworks/compute_box/92000A318_Passivated%2018-8%20Stainless%20Steel%20Pan%20Head%20Phillips%20Screws.SLDPRT) | Panel-mounting screws |
| [`69915K54_Plastic Submersible Cord Grip.SLDPRT`]({{ site.github_blob }}/SPROUT_Design/CAD/Solidworks/compute_box/69915K54_Plastic%20Submersible%20Cord%20Grip.SLDPRT) | Cable gland for battery wiring pass-through |

## Pneumatic fittings

| File | Description |
|---|---|
| [`5602K14_Industrial Quick-Disconnect Hose Coupling Set for Air.SLDPRT`]({{ site.github_blob }}/SPROUT_Design/CAD/Solidworks/compute_box/5602K14_Industrial%20Quick-Disconnect%20Hose%20Coupling%20Set%20for%20Air.SLDPRT) | Quick-disconnect air coupling |
| [`5779K109_Push-to-Connect Tube Fitting for Air.SLDPRT`]({{ site.github_blob }}/SPROUT_Design/CAD/Solidworks/compute_box/5779K109_Push-to-Connect%20Tube%20Fitting%20for%20Air.SLDPRT) | Push-to-connect fitting |
| [`5779K131_Push-to-Connect Tube Fitting for Air.SLDPRT`]({{ site.github_blob }}/SPROUT_Design/CAD/Solidworks/compute_box/5779K131_Push-to-Connect%20Tube%20Fitting%20for%20Air.SLDPRT) | Push-to-connect fitting |
| [`5779K24_Push-to-Connect Tube Fitting for Air.SLDPRT`]({{ site.github_blob }}/SPROUT_Design/CAD/Solidworks/compute_box/5779K24_Push-to-Connect%20Tube%20Fitting%20for%20Air.SLDPRT) | Push-to-connect fitting |
| [`5779K445_Push-to-Connect Tube Fitting for Air.SLDPRT`]({{ site.github_blob }}/SPROUT_Design/CAD/Solidworks/compute_box/5779K445_Push-to-Connect%20Tube%20Fitting%20for%20Air.SLDPRT) | Push-to-connect fitting |
| [`7699N53_Universal-Thread Push-to-Connect Tube Fittings.SLDPRT`]({{ site.github_blob }}/SPROUT_Design/CAD/Solidworks/compute_box/7699N53_Universal-Thread%20Push-to-Connect%20Tube%20Fittings.SLDPRT) | Universal-thread push-to-connect fitting |
| [`4830K133_Standard-Wall 304-304L Stainless Steel Pipe Nipple.SLDPRT`]({{ site.github_blob }}/SPROUT_Design/CAD/Solidworks/compute_box/4830K133_Standard-Wall%20304-304L%20Stainless%20Steel%20Pipe%20Nipple.SLDPRT) | Stainless steel pipe nipple |

See the [Bill of Materials]({{ site.baseurl }}/documentation/bom.html#pneumatics) for the matching McMaster-Carr/vendor part numbers.

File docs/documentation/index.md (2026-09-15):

---
layout: default
title: Documentation
nav_order: 2
has_children: true
permalink: /documentation/
---

# Documentation
{: .no_toc }

## Overview

This section provides build documentation for SPROUT: The Open-Source Soft
Robot for Search and Rescue. It covers two subsystems:

- **Compute box** — onboard computation, power regulation, actuator control,
  sensing interfaces, networking, and embedded communication hardware. See
  [Bill of Materials]({{ site.baseurl }}/documentation/bom.html),
  [Enclosure]({{ site.baseurl }}/documentation/enclosure.html),
  [Assembly]({{ site.baseurl }}/documentation/assembly.html), and
  [Wiring]({{ site.baseurl }}/documentation/wiring.html).
- **Vine robot body** — the soft, pneumatically-actuated "vine" that everts
  from the base and is driven by the compute box. See
  [Vine Construction]({{ site.baseurl }}/documentation/vine-construction.html).

Mechanical CAD for both subsystems, plus the robot base, is covered separately
under [CAD]({{ site.baseurl }}/cad/).

The system is designed for:
- field deployment
- modular servicing
- battery-powered operation
- rapid hardware iteration
- reproducible research integration

---

## Documentation map

| Page | Description |
|---|---|
| [Bill of Materials]({{ site.baseurl }}/documentation/bom.html) | Bill of materials and sourcing |
| [Enclosure]({{ site.baseurl }}/documentation/enclosure.html) | Enclosure preparation and mounting layout |
| [Assembly]({{ site.baseurl }}/documentation/assembly.html) | Step-by-step assembly procedure |
| [Wiring]({{ site.baseurl }}/documentation/wiring.html) | Wiring harnesses and connector pinouts |
| [Vine Construction]({{ site.baseurl }}/documentation/vine-construction.html) | Fabricating the vine robot body |

---

## Compute box

### System architecture

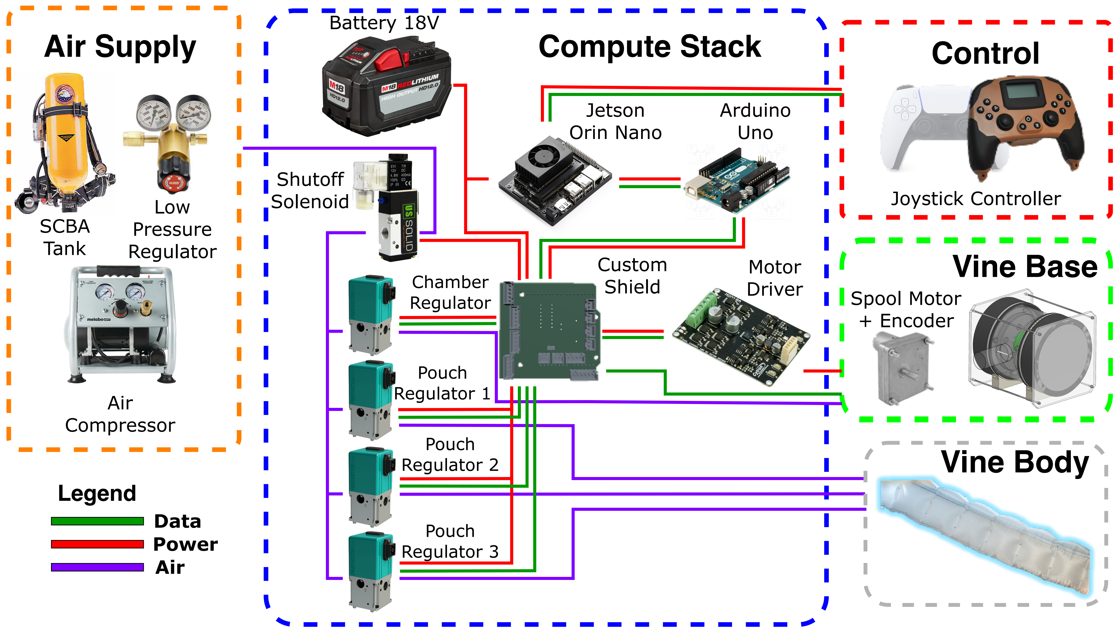
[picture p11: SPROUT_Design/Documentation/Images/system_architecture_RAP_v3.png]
System Architecture


The compute stack coordinates communication between:
- embedded microcontrollers
- motor drivers
- sensing hardware
- pneumatic regulators
- operator interfaces
- power regulation hardware

Major subsystems include:
- Compute Stack
- Control Peripherals
- Vine Base

### Compute hardware

| Component | Function |
|---|---|
| NVIDIA Jetson | Main onboard compute |
| Arduino Uno Rev3 | Low-level actuator/sensor interface |
| DC-DC regulators | Power conversion |
| Motor drivers | Actuator control |

### Power architecture

The compute box operates from an external DC battery source.

Primary voltage rails:
- 18 V actuator rail
- 15 V auxiliary rail
- 5 V compute rail

All rails are fused independently.

### Communication architecture

The system currently uses:
- USB serial communication
- Ethernet
- WiFi

### Assembly workflow

Recommended assembly order:

1. Mechanical enclosure preparation
2. Component mounting
3. Power subsystem wiring
4. Compute subsystem installation
5. Peripheral wiring
6. Software flashing/setup
7. Validation testing

### Safety

{: .warning }
> Disconnect all power before servicing the compute box.
>
> Verify voltage polarity prior to powering up the system.
>
> Use strain relief for all external cable interfaces.

---

## Vine robot body

The vine body is a soft, pneumatically-actuated structure fabricated from
heat-sealable TPU-coated fabric — see [Vine Construction]({{ site.baseurl }}/documentation/vine-construction.html)
for the full fabrication procedure, materials, and inspection/test steps.

{: .warning }
> Overheating the impulse sealer during fabrication can ruin hours of work in
> seconds; underheating can produce a body that bursts at low actuation
> pressures. See [Vine Construction → Workspace and equipment preparation]({{ site.baseurl }}/documentation/vine-construction.html#workspace-and-equipment-preparation).

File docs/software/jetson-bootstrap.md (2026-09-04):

---
layout: default
title: Jetson Bootstrap
parent: Compute Setup
grand_parent: Software
nav_order: 1
---

# Jetson Nano Bootstrap
{: .no_toc }

Source: [`.../compute_setup/jetson/README.md`]({{ site.github_blob }}/SPROUT_Design/Code/compute_setup/jetson/README.md)
{: .label .label-green }

Helpful guides on how to install the ROS 2-ready system on the Jetson Orin
Nano. The following instructions utilize an SSD to flash the Nano image. We
recommend at least a 1 TB SSD installed into the NVMe SSD slot on the bottom
of the Jetson.

## Table of contents
{: .no_toc .text-delta }

- TOC
{:toc}

---

## Flashing JetPack to the device

Follow the [official instructions available from NVIDIA](https://www.jetson-ai-lab.com/initial_setup_jon.html). We recommend using the instructions in the *Alternative method: SDK Manager* section.

We suggest using JetPack 6.1.X. The host computer used to flash the Jetson must run Ubuntu 20/22.

After flashing, boot the device, and proceed to set up a user name and password. We recommend naming the device `jetson`. For ease of use, we recommend setting the device to auto-login. Do not install the Chromium browser.

{: .warning }
> Skip Chromium during first-boot setup — the default package source is broken (see [Fixing Chromium](#fixing-chromium) below for a working install method).

## Increasing performance

Follow the [instructions](https://developer.nvidia.com/embedded/learn/get-started-jetson-orin-nano-devkit#maxn) from NVIDIA to switch the device to MAXN SUPER mode, which will operate the device with up to 25 W of power.

## Fixing Chromium

By default, the default source for the Chromium web browser is broken. Use the following commands to get a working version.

```bash
sudo apt update
sudo apt install flatpak
flatpak remote-add --if-not-exists flathub https://dl.flathub.org/repo/flathub.flatpakrepo
flatpak install flathub org.chromium.Chromium
```

## Installing ROS 2

```bash
sudo apt update
sudo apt install -y curl gnupg2 lsb-release build-essential
sudo curl -sSL https://raw.githubusercontent.com/ros/rosdistro/master/ros.key -o /usr/share/keyrings/ros-archive-keyring.gpg
echo "deb [signed-by=/usr/share/keyrings/ros-archive-keyring.gpg] http://packages.ros.org/ros2/ubuntu $(lsb_release -cs) main" | \
  sudo tee /etc/apt/sources.list.d/ros2.list > /dev/null
sudo apt update
sudo apt install -y ros-humble-desktop
source /opt/ros/humble/setup.bash
echo "source /opt/ros/humble/setup.bash" >> ~/.bashrc
source ~/.bashrc
```

### Install Visual Studio Code

```bash
cd ~/Downloads
wget https://update.code.visualstudio.com/1.77.3/linux-deb-arm64/stable
sudo dpkg -i stable
```

## Installing necessary system packages

```bash
sudo apt install -y \
  python3-colcon-common-extensions \
  python3-rosdep \
  python3-vcstool \
  python3-pip \
  git \
  nano \
  htop \
  nvidia-cuda \
  nvidia-tensorrt \
  nvidia-opencv \
  terminator \
  libhidapi-dev
```

JTOP is the recommended system monitoring tool for processor/GPU performance. It must be installed with `sudo`.

```bash
sudo pip3 install -U jetson-stats
```

### Creating a colcon workspace

```bash
mkdir -p ~/ws/src
cd ~/ws
colcon build
```

We also add a utility command to assist with rebuilding the repo:

```bash
echo "alias build_ros='cd ~/ws && colcon build && source install/setup.bash'" >> ~/.bashrc
```

## Switch desktop to XFCE

By default the desktop on the Jetson consumes around 1 GB of RAM during idle operation. We can improve that by switching to a lightweight desktop.

```bash
sudo apt-get install xfce4
```

After installing, log out, then when you log back in select the gear icon near the login button to change the desktop session to xfce. This change will persist the next time you log in.

## Configure ports on the joystick controller and Arduino

Follow the dedicated [USB device rules guide]({{ site.baseurl }}/software/usb-rules.html) to set up the various required and optional device connections.

## Configure ROS workspace

Move into the ROS workspace, clone necessary packages, and build the repo.

```bash
cd ~/ws/src
git clone git@github.com:SPROUT-MITLL/sprout_ros.git # Install SPROUT ROS
git clone -b ros2 git@github.com:SPROUT-MITLL/ds5_ros.git # SPROUT fork of DS5 driver
cd ~/ws
colcon build
source ../devel/setup.bash
```

## Install Arduino IDE

These instructions will download an app image containing the Arduino IDE for an ARM64 device.

```bash
cd Downloads
wget https://github.com/koendv/arduino-ide-raspberrypi/releases/download/2.2.0/Linux_arm64_app_image.zip
unzip Linux_arm64_app_image.zip
chmod +x arduino-ide_2.2.1_Linux_arm64.AppImage # Make the app image executable
./arduino-ide_2.2.1_Linux_arm64.AppImage # Run the app image
```

Allow the application to initialize and install necessary packages upon first system boot. The [Encoder](https://docs.arduino.cc/libraries/encoder/) package is the only non-default package required to compile the sketch.

## Flash Arduino with code

Connect the Arduino to the Jetson via USB cable.

Open the Arduino sketch: `~/ws/src/sprout_ros/arduino/vine_control/vine_control/vine_control_uno_rev3`

Make sure the IDE is connected to the Arduino Uno on `/dev/ttyACM0`. Verify and upload the sketch to the device.

Once `Upload Finished` is displayed, the device is ready to use!

## Adding the screen

We need to enable the Jetson Nano to communicate with the LCD screen over GPIO. First run the following commands to enable software access.

```bash
sudo apt-get update
sudo pip3 install Jetson.GPIO
sudo groupadd -f -r gpio
sudo usermod -a -G gpio <<USER_NAME>>
```

Power off the Jetson, and unplug from the power source. Use the wiring guide below to connect the LCD screen to the Jetson using jumper wires.

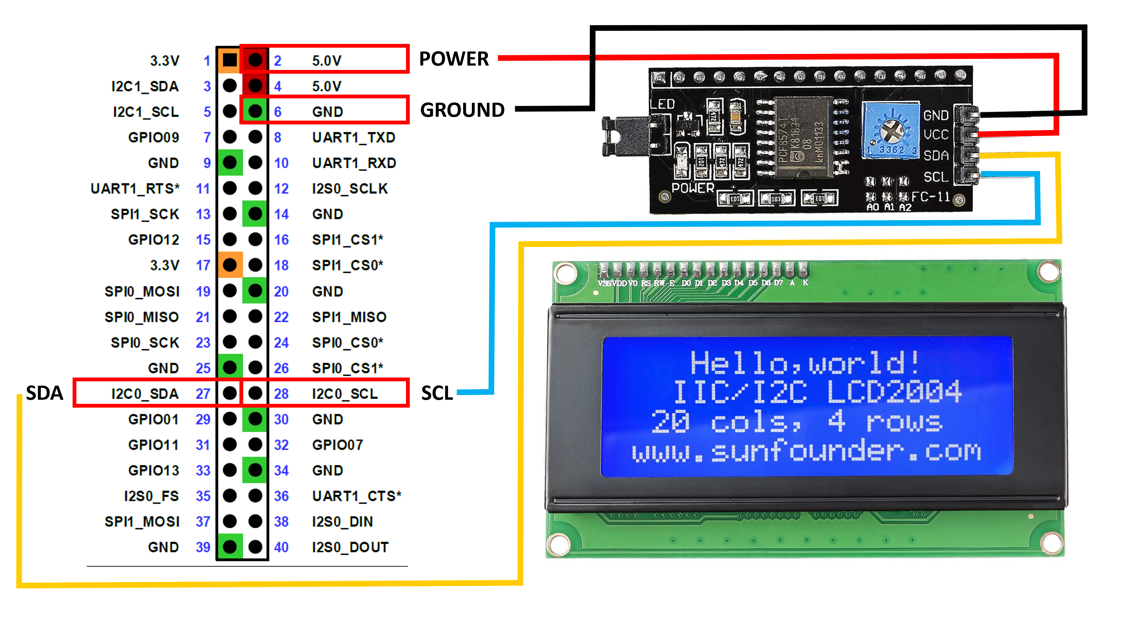
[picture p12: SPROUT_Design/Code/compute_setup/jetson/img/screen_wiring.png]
Jetson Nano Screen Wiring Guide


## Start ROS nodes automatically

{: .important }
> If you named your user something other than `jetson` during setup, modify the home directory under the `ExecStart` command in `sprout_ros.service`.

```bash
sudo cp ~/ws/src/sprout_ros/resource/sprout_ros.service /etc/systemd/system/
sudo systemctl enable sprout_ros.service
```

In order to allow USB devices access on boot, we will need to give permission to unprivileged users.

```bash
cd /etc/udev/rules.d/
sudo touch local.rules
sudo nano local.rules
```

Add the following line into the file.

```
ACTION=="add", KERNEL=="dialout", MODE="0666"
```

Reboot the system: `sudo reboot now`

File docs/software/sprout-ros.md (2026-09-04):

---
layout: default
title: SPROUT ROS
parent: Software
nav_order: 2
---

# SPROUT ROS
{: .no_toc }

Source: [`SPROUT_Design/Code/sprout_ros`]({{ site.github_tree }}/SPROUT_Design/Code/sprout_ros)
{: .label .label-green }

ROS 2 stack for SPROUT. Main installation instructions live in the [Jetson Bootstrap]({{ site.baseurl }}/software/jetson-bootstrap.html) guide; this page summarizes the package layout.

## Table of contents
{: .no_toc .text-delta }

- TOC
{:toc}

---

## Package layout

The `sprout_ros` package (`ament_cmake`, ROS 2) is organized as follows:

| Path | Contents |
|---|---|
| [`arduino/vine_control`]({{ site.github_tree }}/SPROUT_Design/Code/sprout_ros/arduino/vine_control) | `vine_control_uno_rev3` Arduino sketch that runs on the Uno Rev3 and talks to the shield hardware |
| [`launch/system_bringup.py`]({{ site.github_blob }}/SPROUT_Design/Code/sprout_ros/launch/system_bringup.py) | Top-level launch file that brings up the Fort controller, Arduino interface, and LCD screen nodes |
| [`msg/`]({{ site.github_tree }}/SPROUT_Design/Code/sprout_ros/msg) | `Command.msg` and `State.msg` message definitions |
| [`scripts/`]({{ site.github_tree }}/SPROUT_Design/Code/sprout_ros/scripts) | ROS 2 node implementations (controller drivers, vine interface, display, camera) |
| [`srv/`]({{ site.github_tree }}/SPROUT_Design/Code/sprout_ros/srv) | `PressureSet.srv` service definition |
| [`resource/`]({{ site.github_tree }}/SPROUT_Design/Code/sprout_ros/resource) | systemd service unit for auto-starting the stack on boot |

## Messages and services

**`Command.msg`** — teleop command sent to the vine robot driver:

```
bool toggle_retract
bool grow_speed_inc
bool grow_speed_dec
bool chamber_inc
bool chamber_dec
bool stop_grow
bool estop
float32 steer_ud
float32 steer_lr
```

**`State.msg`** — robot state feedback (pressure sensor and actuator values):

```
float32 cp_s
float32 a1_s
float32 a2_s
float32 a3_s
float32 cp_a
float32 a1_a
float32 a2_a
float32 a3_a
float32 d_s
float32 d_c
float32 c_m
float32 a_m
```

**`PressureSet.srv`** — request/response for setting a chamber/actuator pressure target:

```
float32 chamber_val
float32 actuator_val
---
bool success
string message
```

## Nodes

| Script | Description |
|---|---|
| [`fort_controller.py`]({{ site.github_blob }}/SPROUT_Design/Code/sprout_ros/scripts/fort_controller.py) | Reads the Fort Robotics Wireless Controller (FRWC) HID device directly and publishes `sensor_msgs/Joy` |
| [`fort_scm_controller.py`]({{ site.github_blob }}/SPROUT_Design/Code/sprout_ros/scripts/fort_scm_controller.py) | Publishes `Joy` messages using the `fort_scm` SCM protocol library for the Fort controller |
| [`joy_vine_interface.py`]({{ site.github_blob }}/SPROUT_Design/Code/sprout_ros/scripts/joy_vine_interface.py) | Bridges `Joy` messages to the vine robot's Arduino over serial, publishing `sprout_ros/State` |
| [`fort_vine_interface.py`]({{ site.github_blob }}/SPROUT_Design/Code/sprout_ros/scripts/fort_vine_interface.py) | Variant of the vine interface driver that also exposes the `PressureSet` service |
| [`screen.py`]({{ site.github_blob }}/SPROUT_Design/Code/sprout_ros/scripts/screen.py) | Drives the onboard status LCD from `sprout_ros/State` |

## Bring-up

`launch/system_bringup.py` starts the Fort controller driver, the Arduino/vine interface node, and the LCD screen node together:

```python
Node(package='sprout_ros', executable='fort_scm_controller.py', name='fort_driver', output='screen'),
Node(package='sprout_ros', executable='fort_vine_interface.py', name='jetson_arduino', output='screen'),
Node(package='sprout_ros', executable='screen.py', name='jetson_screen', output='screen'),
```

## Arduino firmware

The `vine_control` sketch (`arduino/vine_control/vine_control/vine_control_uno_rev3`) runs on the Arduino Uno Rev3 mounted on the [custom shield]({{ site.baseurl }}/electronics/) and is flashed following the [Jetson Bootstrap]({{ site.baseurl }}/software/jetson-bootstrap.html#flash-arduino-with-code) guide.

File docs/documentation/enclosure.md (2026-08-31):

---
layout: default
title: Enclosure
parent: Documentation
nav_order: 2
---

# Enclosure Preparation and Mounting Layout
{: .no_toc }

This page describes the preparation and mounting layout of the compute box
enclosure used in the SPROUT robotic platform. The enclosure integrates
compute hardware, power electronics, communication interfaces, and
electropneumatic control hardware while maintaining portability and
environmental protection.

The mounting architecture was designed to:
- preserve enclosure waterproofing
- minimize permanent enclosure modification
- support modular servicing
- allow repeatable assembly

## Table of contents
{: .no_toc .text-delta }

- TOC
{:toc}

---

## Primary components

| Component | Manufacturer/Source | Link |
|---|---|---|
| NANUK 930 Empty Case | NANUK | [Link](https://nanukcases.ca/products/nanuk-930-empty) |
| ABS Mounting Plate for Junction Box | Amazon | [Link](https://www.amazon.com/LeMotech-Junction-Mounting-Installation-Electrical/dp/B0CGCS2C4B) |

The ABS mounting plate serves as the primary internal mounting surface for
compute hardware, power electronics, and electropneumatics.

## Provided CAD files

STL files and CAD assemblies for all mounting components are provided in
[CAD → Compute Box]({{ site.baseurl }}/cad/new-compute-box.html).

---

## General enclosure preparation

Prior to any mounting or adhesive bonding operations, the enclosure interior
should be cleaned thoroughly.

Recommended procedure:

1. Remove all foam inserts and debris from the enclosure.
2. Wipe internal surfaces using isopropyl alcohol (IPA).
3. Allow all surfaces to dry completely before proceeding.

Before adhesive bonding, all bonding regions should be lightly roughened using
sandpaper and cleaned again using IPA.

---

## Internal mounting system

### Mounting plate design

Custom corner brackets were designed to secure the ABS mounting plate to the
enclosure interior. These brackets are custom 3D printed and conform directly
to the interior geometry of the NANUK 930 enclosure.

To ensure accurate fitment, the enclosure interior surface CAD model was
obtained from the manufacturer and imported into SolidWorks. The mounting
brackets were designed directly against the enclosure geometry to maximize
bonding area, maintain mounting plate alignment, and minimize internal stress
during assembly.

Each corner bracket contains M5 heat-set threaded inserts that interface
directly with the ABS mounting plate hardware. STL files for all mounting
components are provided in the [CAD]({{ site.baseurl }}/cad/) section. Install the heat-set
inserts to the brackets before adhering them to the case.

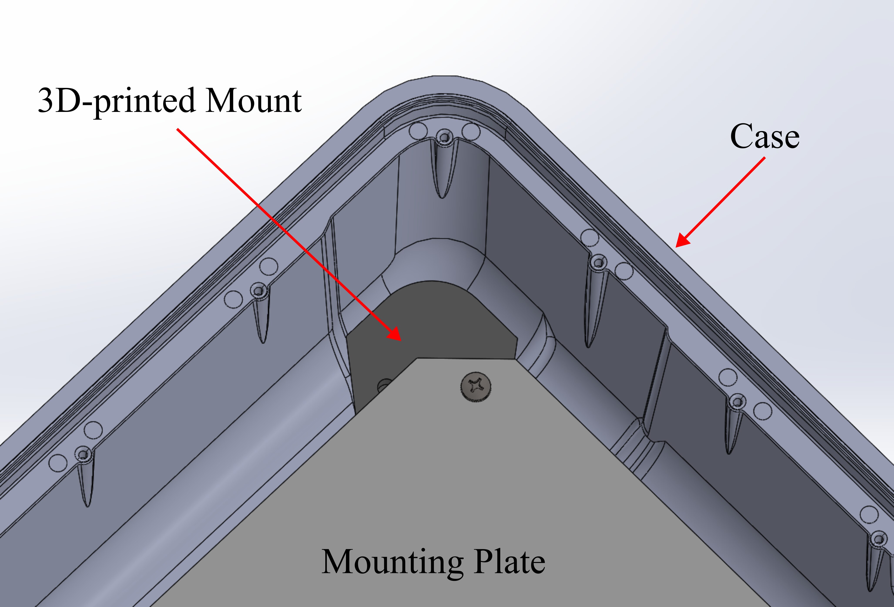
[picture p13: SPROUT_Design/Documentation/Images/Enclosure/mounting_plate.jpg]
Corner Mount Overview


*Figure 1. Internal corner mounting brackets used to secure the mounting plate.*

### Bonding procedure

The corner mounting brackets are permanently attached to the enclosure using
two-part clear epoxy.

Recommended procedure:

1. Prepare epoxy according to manufacturer instructions.
2. Apply epoxy evenly to the bonding surfaces of each corner bracket.
3. Position the bracket within the enclosure corners.
4. Verify mounting plate alignment before curing.
5. Allow full adhesive cure prior to mechanical loading.

{: .important }
> Do not mount hardware to the brackets or subject them to load until the epoxy has fully cured — loading them early can weaken the bond permanently.

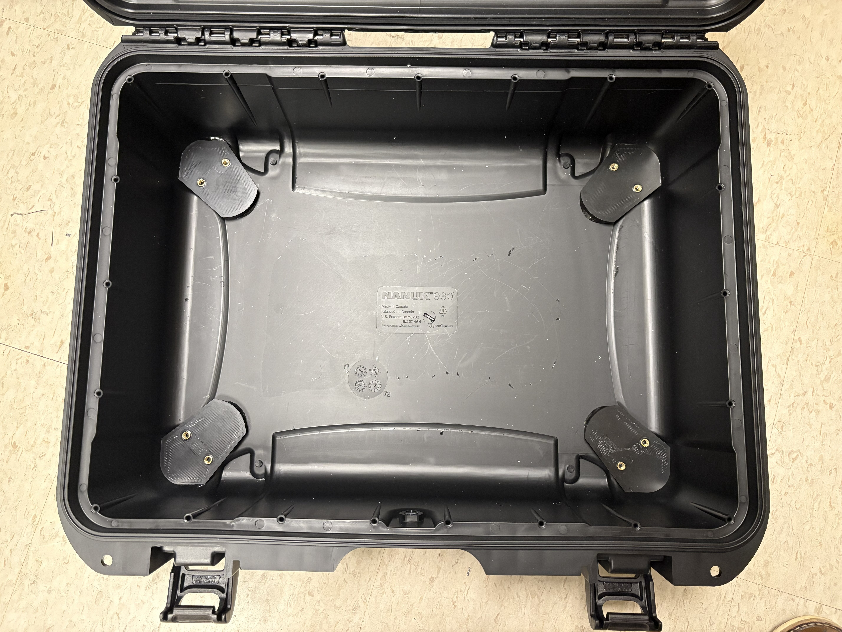
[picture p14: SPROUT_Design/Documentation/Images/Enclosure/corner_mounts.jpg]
Bonded Corner Mounts


*Figure 2. Epoxied internal mounting brackets with integrated heat-set inserts.*

### Top interface plate mounts

Additional custom 3D printed brackets are used to support the top acrylic
interface plate. These mounting brackets were designed using the same
enclosure interior CAD geometry and use the same epoxy bonding procedure
described previously. There are 4 of these brackets, one for each corner.

The brackets contain M5 heat-set threaded inserts and support the acrylic
interface plate used for external connectors, display hardware, user interface
peripherals, and power switches.

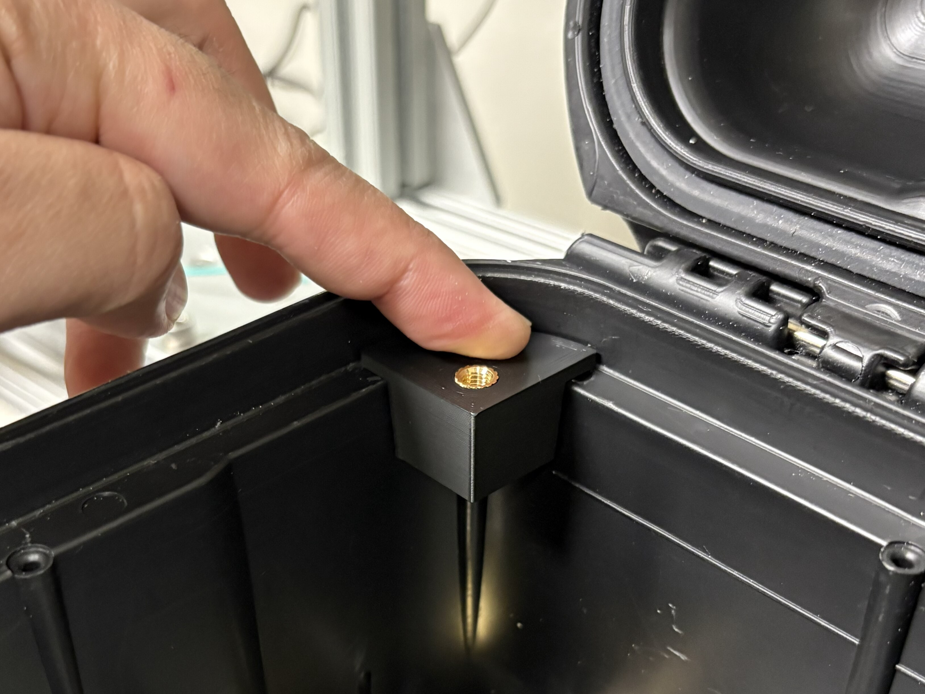
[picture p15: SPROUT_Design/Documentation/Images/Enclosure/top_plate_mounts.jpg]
Top interface plate mounting system


*Figure 3. Top interface plate mounting system.*

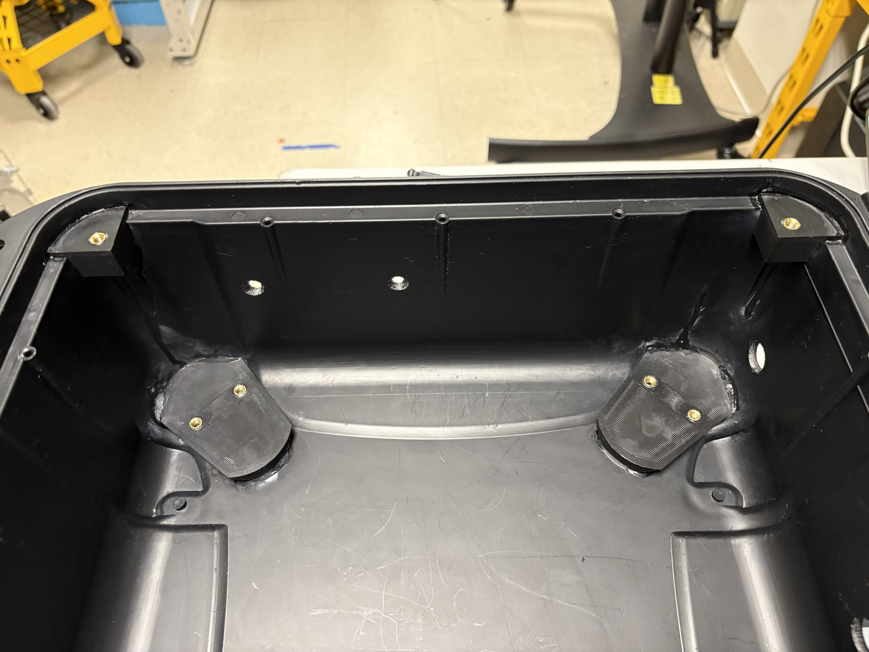
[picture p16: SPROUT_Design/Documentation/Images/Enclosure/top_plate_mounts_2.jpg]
Top interface plate mounting system


*Figure 4. Top interface plate and mounting plate brackets.*

---

## External robot mounting system

Additional external mounting hardware was designed to allow the compute box to
interface mechanically with the robot body. The mounting system is attached to
the underside of the enclosure and allows the compute box to remain securely
seated on the cylindrical body structure of the robot.

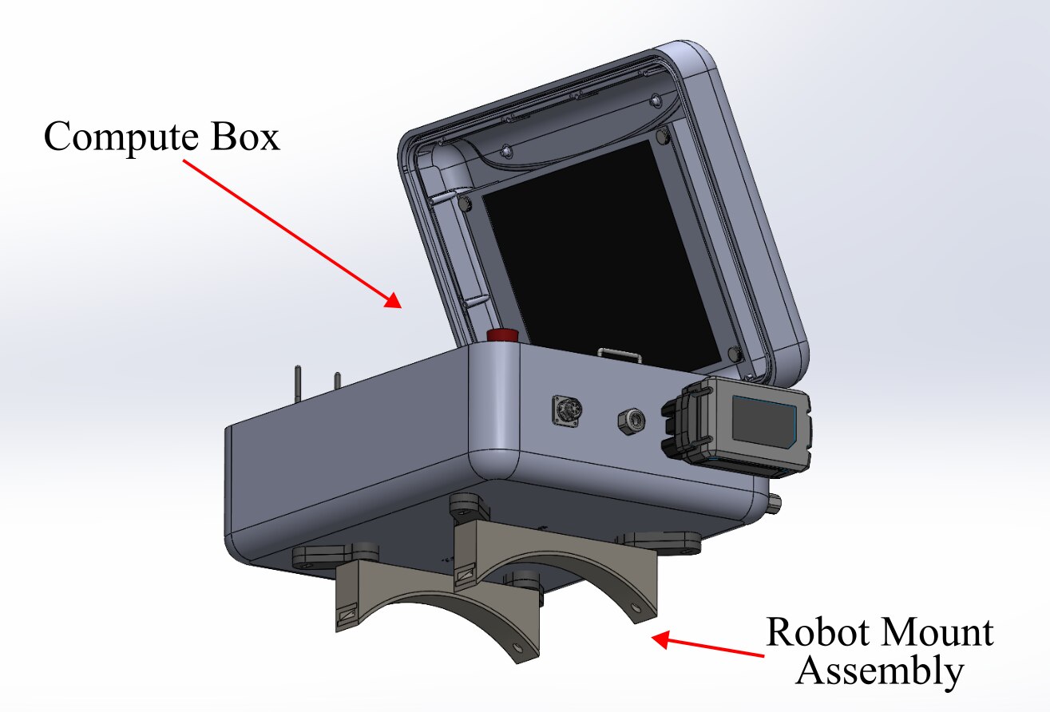
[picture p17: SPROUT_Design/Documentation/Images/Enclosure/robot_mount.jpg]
External robot mounting assembly attached to the underside of the enclosure.


*Figure 5. External robot mounting assembly attached to the underside of the enclosure.*

Unlike the enclosure interior geometry, the exterior shell CAD for the NANUK
930 enclosure was not available from the manufacturer. As a result, the
external mounting system was developed through manual measurements and
iterative CAD refinement. The geometry was adjusted through repeated test
fitting to achieve stable seating, proper enclosure fitment, and sufficient
clearance for enclosure hardware and interfaces.

### Mounting assembly

The robot mounting assembly consists of:
- a primary mounting bracket bonded directly to the enclosure
- an adjustment bracket with slotted mounting hole
- a curved support foot assembly

The primary mounting brackets are custom 3D printed and bonded to the
enclosure underside using two-part epoxy. These brackets contain heat-set
threaded inserts that provide the structural interface for the remaining
mounting hardware.

The adjustment plates allow lateral positioning and alignment tuning relative
to the robot body. The curved support feet were designed to match the
cylindrical profile of the robot and improve seating stability during
operation.

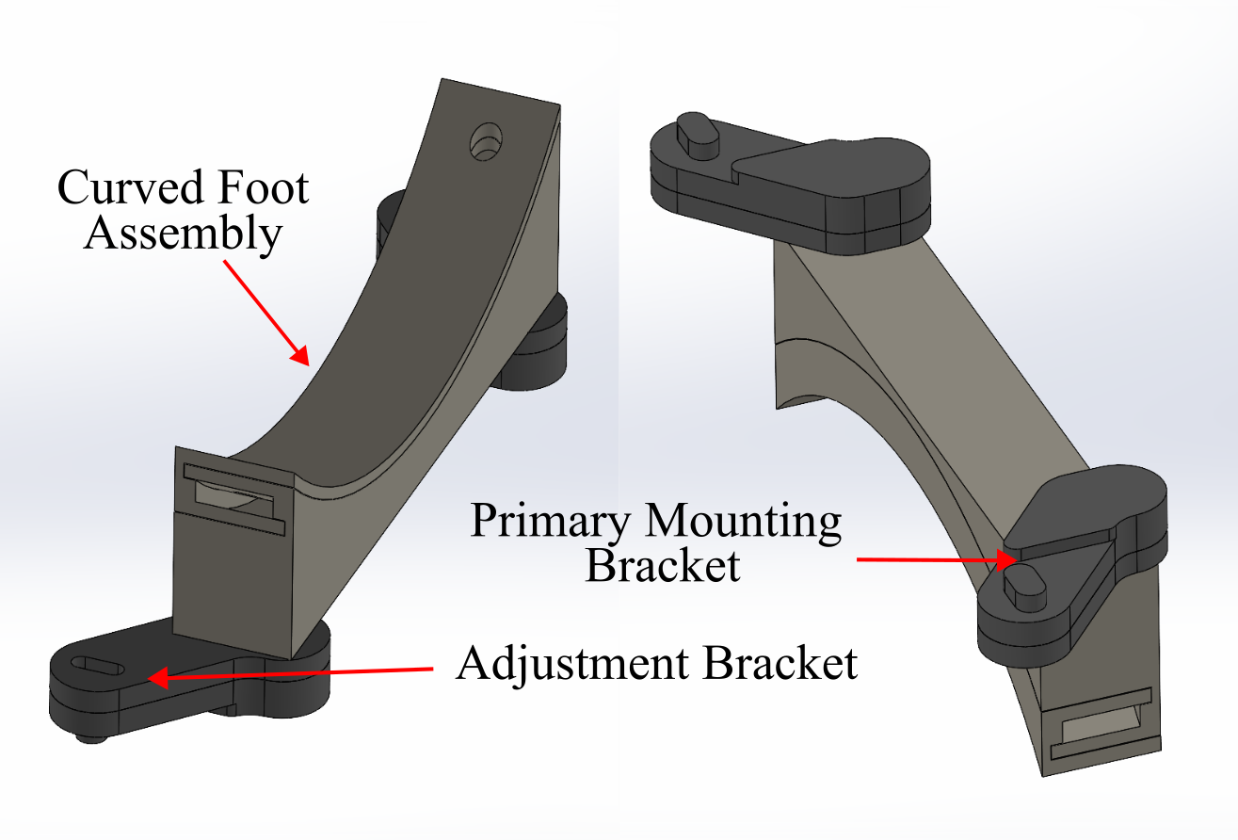
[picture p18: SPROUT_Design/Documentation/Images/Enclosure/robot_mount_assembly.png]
External robot mounting brackets and support feet assembly.


*Figure 6. External robot mounting brackets and support feet assembly.*

First, 3D-print the primary bracket mounts (4), install M5 heat-set inserts, and
epoxy them to the bottom of the case.

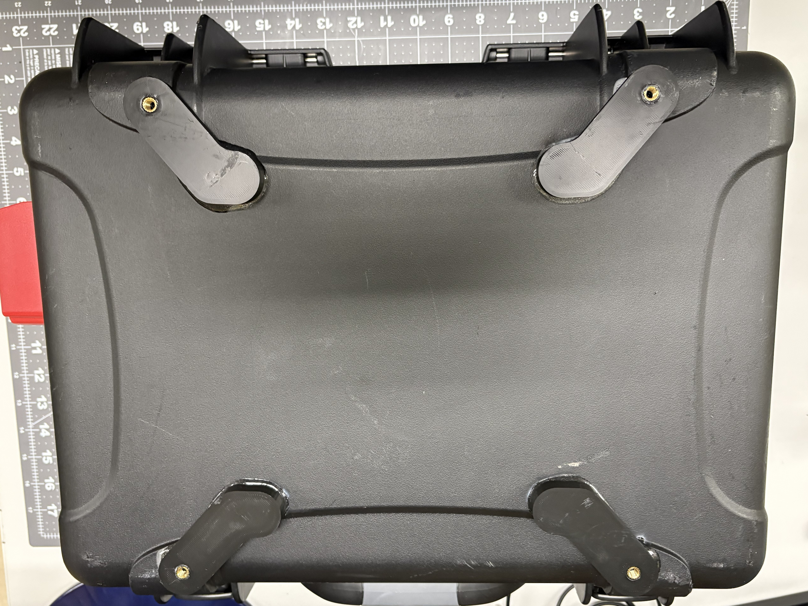
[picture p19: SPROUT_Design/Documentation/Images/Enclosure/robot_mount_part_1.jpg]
Primary brackets epoxied to the bottom of the case.


*Figure 7. Primary brackets epoxied to the bottom of the case.*

Then, 3D-print and assemble the curved foot assembly (2 sets). It is composed
of two parts that slide and attach together. A few drops of super glue around
the inner edges of the parts will make sure the parts are bonded strongly.

Next, 3D-print the adjustment brackets (4) and install M5 heat-set inserts.
Then, use M5 fasteners to attach these to the foot assembly.

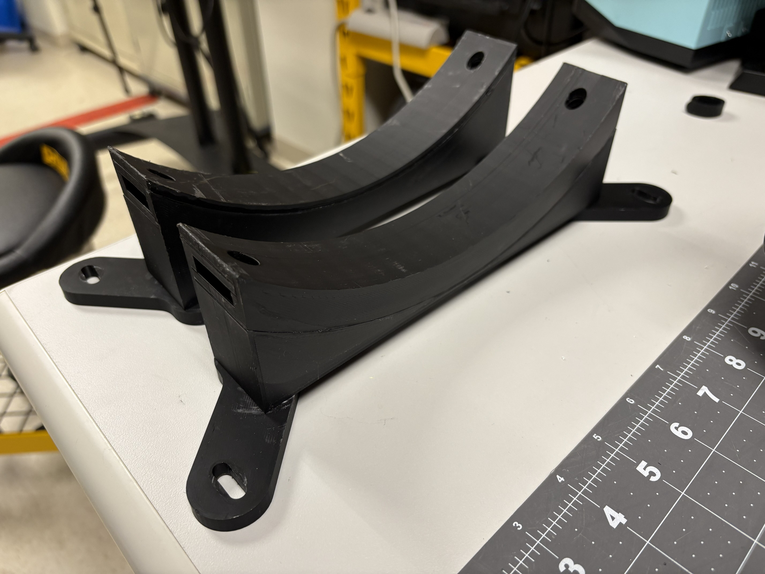
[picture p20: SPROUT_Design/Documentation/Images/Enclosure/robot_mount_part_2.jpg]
Curved foot assembly attached to the adjustment brackets.


*Figure 8. Curved foot assembly attached to the adjustment brackets.*

Lastly, use M5 fasteners to attach the assembly to the primary mounting
brackets.

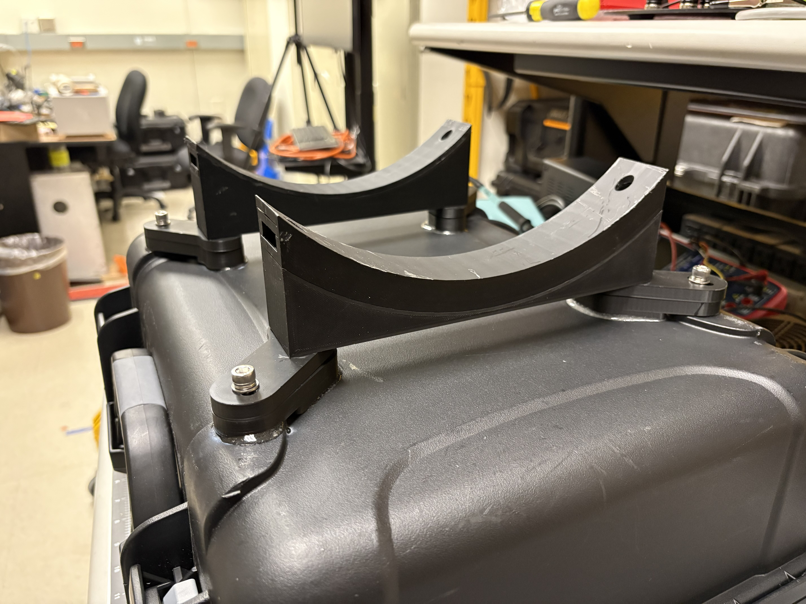
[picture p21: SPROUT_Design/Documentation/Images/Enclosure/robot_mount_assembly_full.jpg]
Installed external robot mounting assembly.


*Figure 9. Installed external robot mounting assembly.*

---

## Screen mounting assembly

The last step in preparing the enclosure is to attach mounting structure for
installing a screen. This screen is placed inside the lid of the case, so that
when the case is opened, the user can see the peripherals panel in the bottom
and the screen in the lid, like a laptop.

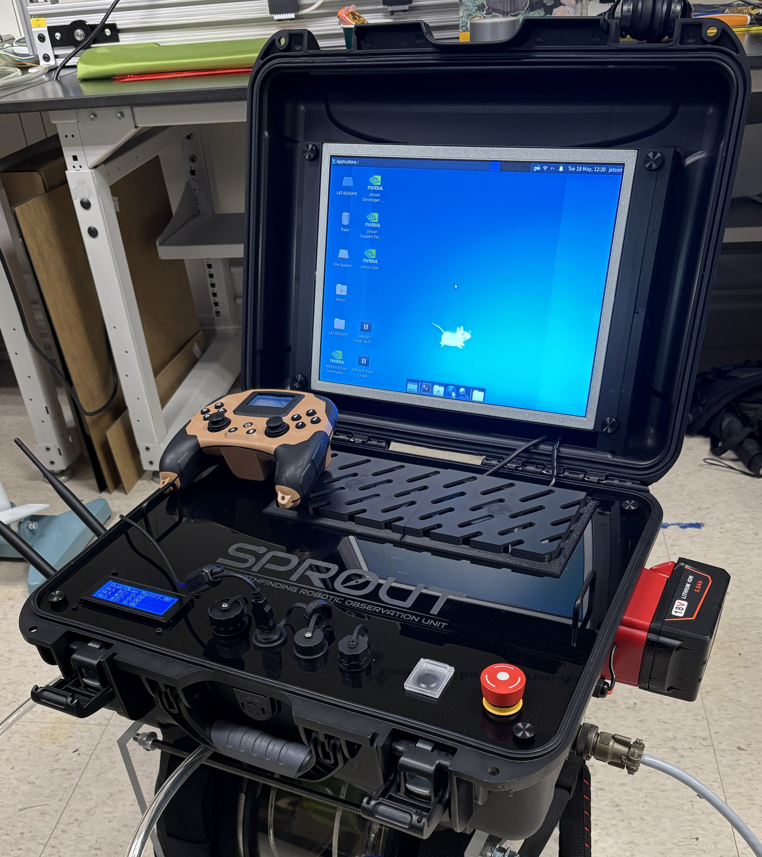
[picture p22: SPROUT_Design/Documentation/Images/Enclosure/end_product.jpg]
Peripheral panel and screen.


First, 3D print the screen mounting brackets, provided in the [CAD]({{ site.baseurl }}/cad/)
section. These were designed using the inner shell of the case so that they
perfectly rest on the features of the inner wall of the lid. Depending on your
3D-printer bed size, you may need to cut these into two sections so they fit
on the build plate, as shown below.

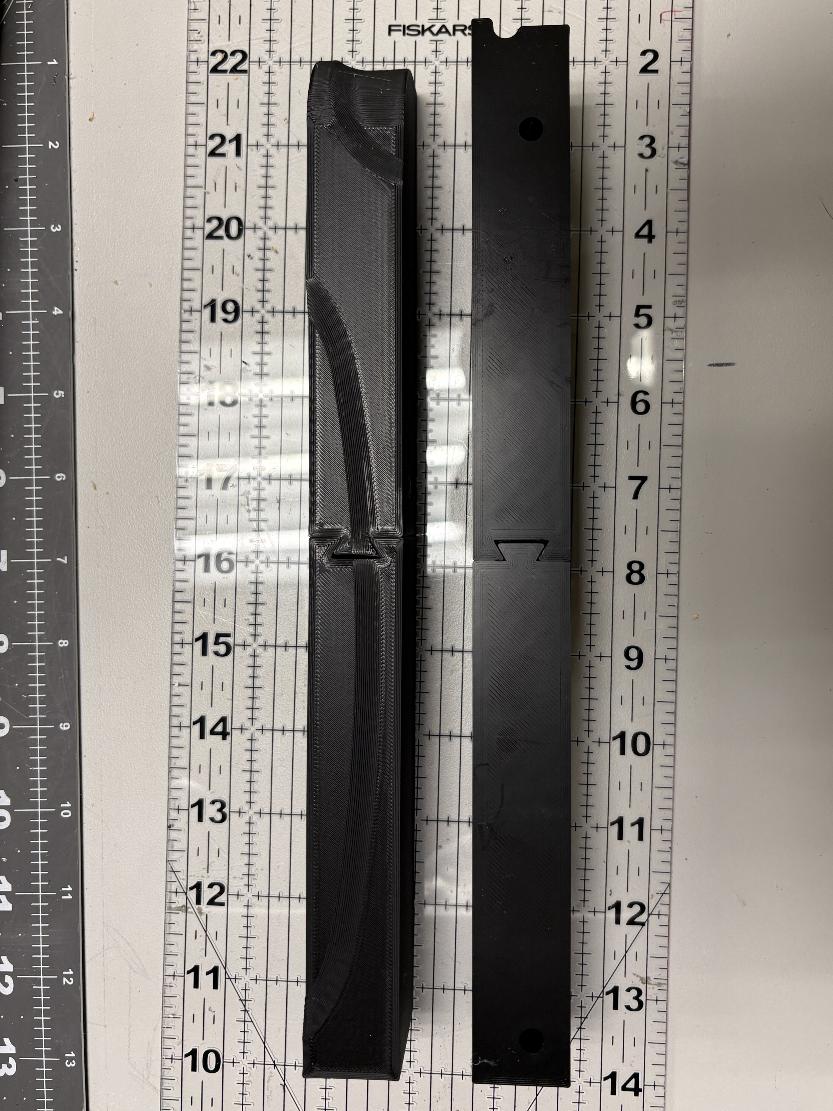
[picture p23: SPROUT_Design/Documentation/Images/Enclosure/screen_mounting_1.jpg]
3D-printed screen mounting brackets.


Install M5 heat-set inserts in the holes (two on each bracket). Adhere the
brackets to the case using epoxy, lining the printed parts with the wall
features, and resting in the bottom of the lid. The end product should look as
below.

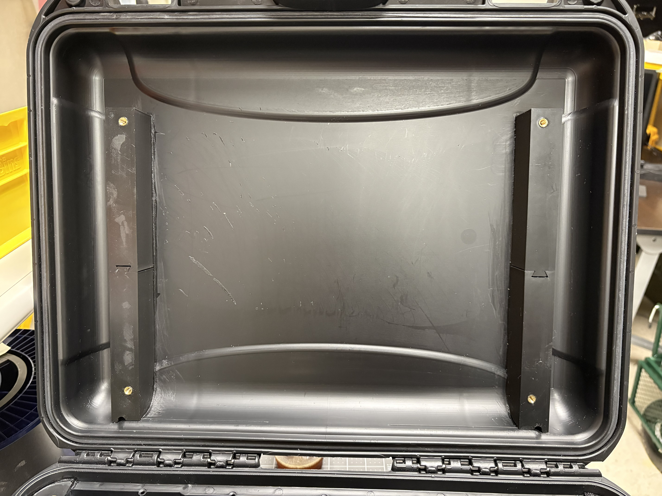
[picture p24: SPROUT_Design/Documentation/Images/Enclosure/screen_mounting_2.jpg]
Installed screen brackets.


Next: continue with the [Compute Box]({{ site.baseurl }}/documentation/assembly.html).

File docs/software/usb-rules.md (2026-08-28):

---
layout: default
title: USB Device Rules
parent: Compute Setup
grand_parent: Software
nav_order: 2
---

# Device Aliasing Setup
{: .no_toc }

Source: [`.../compute_setup/jetson/usb_rules.md`]({{ site.github_blob }}/SPROUT_Design/Code/compute_setup/jetson/usb_rules.md)
{: .label .label-green }

## Table of contents
{: .no_toc .text-delta }

- TOC
{:toc}

---

First, add your user to some groups:

```bash
sudo adduser <<USER>> dialout
sudo adduser <<USER>> video
```

## Setup notes

Do the following to set up access to the Arduino which controls the vine robot base:

```bash
sudo nano /etc/udev/rules.d/99-arduino.rules
```

and then paste in the following:

```
KERNEL=="ttyACM[0-9]*", ACTION=="add", ATTRS{idVendor}=="2341", ATTRS{idProduct}=="0043", SYMLINK+="com/vine_arduino"
```

To put the changes into effect, run

```bash
sudo udevadm control --reload-rules
sudo udevadm trigger
```

and then reboot.

## Connect to PS5 controller

First install the following package to interface with the PS5 controller via python:

```bash
python -m pip install pydualsense pyserial
```

### Via wired cable

Plug the PS5 DualSense controller into one of the Jetson's USB 3.0 ports using a data-cable USB-C cable. Make sure the cable is not just a charging cable!

{: .warning }
> Charge-only USB-C cables are missing the data lines the controller needs and will not work here, even though they charge the controller fine.

Do the following to set up access to the PS5 controller for teleoperation:

```bash
sudo nano /etc/udev/rules.d/70-ps5-controller.rules
```

and then paste in the following:

```
# ref.: https://boilingsteam.com/the-dualsense-is-making-even-more-sense/

# PS5 DualSense controller over USB hidraw
KERNEL=="hidraw*", ATTRS{idVendor}=="054c", ATTRS{idProduct}=="0ce6", MODE="0660", TAG+="uaccess" SYMLINK+="input/ps5"
# PS5 DualSense Edge controller over USB hidraw
KERNEL=="hidraw*", ATTRS{idVendor}=="054c", ATTRS{idProduct}=="0df2", MODE="0660", TAG+="uaccess"  SYMLINK+="input/ps5"
```

To put the changes into effect, run

```bash
sudo udevadm control --reload-rules
sudo udevadm trigger
```

### Via Bluetooth (optional)

Do the following to set up access to the PS5 controller for teleoperation:

```bash
sudo nano /etc/udev/rules.d/70-ps5-controller.rules
```

and then paste in the following:

```
# ref.: https://boilingsteam.com/the-dualsense-is-making-even-more-sense/
# PS5 DualSense controller over bluetooth hidraw
KERNEL=="hidraw*", KERNELS=="*054C:0CE6*", MODE="0660", TAG+="uaccess"  SYMLINK+="input/ps5"
# PS5 DualSense Edge controller over bluetooth hidraw
KERNEL=="hidraw*", KERNELS=="*054C:0DF2*", MODE="0660", TAG+="uaccess"  SYMLINK+="input/ps5"
```

To put the changes into effect, run

```bash
sudo udevadm control --reload-rules
sudo udevadm trigger
```

Pairing can be accomplished in the terminal with the following commands.

Find the computer's Bluetooth device using the command.

```bash
hcitool dev
```

This will return a Bluetooth device name and a MAC address. To find Bluetooth devices in range, run

```bash
hcitool -i <dev_name> scan
```

where `dev_name` is likely `hci0`. The PlayStation 5 DualSense will be called `DualSense Wireless Controller`. Note the MAC address for this device, and then trust and connect to the device using the following commands:

```bash
bluetoothctl  # enters you into some terminal environment
trust <<MAC_address>>
connect <<MAC_address>>
```

## Fort Robotics controller

As an alternative to the PS5 controller, the Fort Robotics Wireless Controller (FRWC) provides a parallel interface.

```bash
sudo nano /etc/udev/rules.d/99-fort-wrc.rules
```

and then paste in the following:

```
KERNEL=="ttyACM[0-9]*", ACTION=="add", ATTRS{idVendor}=="2a99", ATTRS{idProduct}=="c011", MODE="0666", TAG+="uaccess", SYMLINK+="input/fort"
```

To put the changes into effect, run

```bash
sudo udevadm control --reload-rules
sudo udevadm trigger
```

You will also need to install the dedicated package to interface with the Fort Controller.

```bash
cd ~/Downloads
git clone git@github.com:SPROUT-MITLL/fort_scm_py3.git
cd fort_scm_py3
bash build.sh
cd dist
python3 -m pip install <<NAME OF WHL FILE>>
```

## Some useful USB commands

`lsusb` allows you to see connected USB devices. To figure out where a device is connected, run `lsusb` without the device plugged in, and then plug in the device and run again.

`usb-devices` lists all of the USB devices with more information including the vendor ID and product ID which are needed for creating symbolic links to the device.

`dmesg | less` and then hitting `/` and searching for keywords (like the product ID or vendor ID) can also be useful.

`sudo udevadm info --name=<device_name> --attribute-walk` where `<device_name>` is the location of your device on the system (e.g., `/dev/input/js0`). You can also append `| less` to the end of this command to search for the `idVendor` or `idProduct`.

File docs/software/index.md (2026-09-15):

---
layout: default
title: Software
nav_order: 5
has_children: true
permalink: /software/
---

# Software
{: .no_toc }

Source: [`SPROUT_Design/Code`]({{ site.github_tree }}/SPROUT_Design/Code)
{: .label .label-green }

The `Code` directory contains everything needed to bring the compute box's
software stack online: a bootstrap guide for the onboard NVIDIA Jetson, and
`sprout_ros`, the ROS 2 package that drives the vine robot.

## Reference architecture

System Architecture

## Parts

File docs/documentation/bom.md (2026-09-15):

---
layout: default
title: Bill of Materials
parent: Documentation
nav_order: 1
---

# Bill of Materials (BOM)
{: .no_toc }

This page lists the primary hardware components required to assemble the
compute box for the SPROUT platform.

The BOM is organized by subsystem to simplify assembly, troubleshooting, and
future hardware revisions.

## Table of contents
{: .no_toc .text-delta }

- TOC
{:toc}

---

## Overview

### Major subsystems

The compute box consists of the following subsystems:

- Compute hardware
- Power distribution
- Embedded control electronics
- Communication interfaces
- Enclosure hardware
- Wiring

---

## Compute hardware

| Item | Qty | Manufacturer/Source | Part Number | Description | Notes |
|---|---|---|---|---|---|
| NVIDIA Jetson Nano | 1 | NVIDIA | -- | Main onboard computer | 4GB RAM 16G eMMC |
| Arduino Uno Rev3 | 1 | [Amazon](https://www.amazon.com/Arduino-A000066-ARDUINO-UNO-R3/dp/B008GRTSV6/) | -- | Low-level embedded controller | -- |
| 128 GB microSD Card | 1 | [Amazon](https://www.amazon.com/PNY-Premier-X-microSDXC-Memory-2-Pack/dp/B09WBT52KN/) | -- | -- | For Jetson Nano image |
| Dual-Mode Wireless NIC Module with Antennas | 1 | [Amazon](https://www.amazon.com/Wireless-AC8265-Wireless-Developer-Support-Bluetooth/dp/B07SM4SPLV) | -- | -- | -- |

---

## Power distribution

| Item | Qty | Manufacturer/Source | Part Number | Description | Notes |
|---|---|---|---|---|---|
| DC-DC Buck Converter | 5 | [Amazon](https://a.co/d/7YLiOVz) | -- | -- | -- |
| Inline Fuse Holder | 5 | [Amazon](https://amazon.com/Nilight-NI-FH01-Automotive-Holder-10-Warranty/dp/B07426WCLM/) | -- | -- | -- |
| Blade Fuse Kit | 1 | [Amazon](https://www.amazon.com/gp/aw/d/B0B18W5WGB/) | -- | -- | -- |
| M18 Battery | 1 | [Amazon](https://www.amazon.com/dp/B0C9TL93P4) | B0C9TL93P4 | -- | -- |
| Battery Adapter | 1 | [Amazon](https://www.amazon.com/Upgrade-Adapter-Milwaukee-Connector-Robotics/dp/B097JPSFKG?th=1) | -- | -- | -- |
| DC Barrel Plug to Bare Wire Cable | 2 | [Amazon](https://www.amazon.com/Fancasee-Replacement-Degree-Pigtail-Supply/dp/B081TXY6ML) | -- | For Power Adapter use instead of batteries | -- |
| Emergency Stop Switch | 1 | [Mouser](https://mou.sr/42U3Vo7) | 123-84-5220.0020 | -- | -- |
| Push Button Switch | 1 | [Amazon](https://www.amazon.sg/DMWD-Latching-Waterproof-Terminals-Aluminium/dp/B0BJ637Z3H) | B0BJ637Z3H | -- | -- |
| Push Button Cover | 1 | [Amazon](https://www.amazon.sg/Transparent-Switches-Protector-Mounting-Double-Sided/dp/B0CM5W3PBS) | B0CM5W3PBS | -- | -- |
| Plastic Submersible Cord Grip/Gland | 1 | [McMaster-Carr](https://www.mcmaster.com/69915K54/) | 69915K54 | -- | -- |

---

## Embedded control electronics

| Item | Qty | Manufacturer/Source | Part Number | Description | Notes |
|---|---|---|---|---|---|
| DC Motor Driver | 1 | [Cytron](https://www.cytron.io/p-10amp-5v-30v-dc-motor-driver-2-channels) | MDD10A | -- | -- |
| Custom Arduino Shield PCB | 1 | Custom | -- | Interface breakout board | Mounted on Arduino, see [Electronics]({{ site.baseurl }}/electronics/) |
| QB3 Pressure Regulators | 4 | [ProportionAir](https://proportionair.com/product/qb3/) | -- | Pneumatic pressure regulation | -- |
| Solenoid Valve 3/2 NC | 1 | [U.S. Solid](https://ussolid.com/products/u-s-solid-1-4-3-way-2-position-pneumatic-electric-solenoid-valve-dc-12-v-html) | -- | -- | -- |

---

## Pneumatics

| Item | Qty | Manufacturer/Source | Part Number | Description | Notes |
|---|---|---|---|---|---|
| 1/2" Polyurethane Tubing | 2 ft | McMaster-Carr | 5648K78 | -- | -- |
| 1/4" Polyurethane Tubing | 5 ft | McMaster-Carr | 5648K25 | -- | -- |
| 1/4" Pipe Nipples, 3" Long | 5 | McMaster-Carr | 46755K42 | -- | -- |
| 1/2" Push-to-Connect Fitting Plug | 1 | [Amazon](https://www.amazon.com/dp/B08D6LFY9S) | B08D6LFY9S | -- | Plugs for testing/troubleshooting pneumatics |
| 1/4" Push-to-Connect Fitting Plug | 1 | [Amazon](https://www.amazon.com/HJGarden-Connect-Fitting-Pneumatic-Connector/dp/B09FLG61BX/) | B09FLG61BX | -- | Plugs for testing/troubleshooting pneumatics |
| 1/4" Push-to-Connect OD x 1/4" NPT Thread Tee | 1 (Pack of 10) | [Amazon](https://www.amazon.com/dp/B07RY31QH5) | B07RY31QH5 | -- | -- |
| 1/4" Push-to-Connect OD Elbow | 1 (Pack of 10) | [Amazon](https://www.amazon.com/dp/B0B3X2CY13) | B0B3X2CY13 | -- | -- |
| 1/4" Push-to-Connect OD x 1/4" NPT Thread Elbow | 1 (Pack of 10) | [Amazon](https://www.amazon.com/dp/B07GLH22HV) | B07GLH22HV | -- | -- |
| 1/4" Push-to-Connect OD x 1/4" NPT Female | 3 | [McMaster-Carr](https://www.mcmaster.com/5779K131/) | 5779K131 | -- | -- |
| 1/2" Push-to-Connect OD x 1/4" NPT Female | 1 | [McMaster-Carr](https://www.mcmaster.com/5779K445/) | 5779K445 | -- | -- |
| 1/4" NPT Female, Quick Connect Air Coupler | 1 (pack of 10) | [Amazon](https://www.amazon.com/dp/B0C6K1CYN7?th=1) | -- | -- | -- |
| 1/4" NPT Female, Quick Connect Air Plug | 1 (pack of 10) | [Amazon](https://www.amazon.com/dp/B08M3VLL4D) | B08M3VLL4D | -- | -- |
| Through-Wall Adapter, for 1/4" Tube OD Push-to-connect x 1/4 NPT Female | 1 | [McMaster-Carr](https://www.mcmaster.com/5779K272/) | 5779K272 | -- | -- |
| Check Valve, 1/4 NPT Female x NPT Male | 1 | [McMaster-Carr](https://www.mcmaster.com/7768K22/) | 7768K22 | -- | -- |
| Straight Adapter, for 1/4" Tube OD push-to-connect x 1/4 NPT Male | 2 | [McMaster-Carr](https://www.mcmaster.com/5779K109/) | 5779K109 | -- | -- |

---

## Communication interfaces and peripherals

| Item | Qty | Manufacturer/Source | Part Number | Description | Notes |
|---|---|---|---|---|---|
| USB Connector Panel-Mount | 2 | [Amazon](https://a.co/d/8kQKNGa) | -- | External USB access | -- |
| USB 3.0 Cable 1ft Long, A-to-A, Male-to-Male | 2 | [Amazon](https://www.amazon.com/SUNGUY-USB-Cable-Type-Male/dp/B0FB3WJSN5/) | -- | -- | -- |
| DisplayPort to HDMI Cable, 3ft Long | 1 | [Amazon](https://www.amazon.com/Amazon-Basics-Uni-Directional-DisplayPort-Display/dp/B015OW3GJK?th=1) | B015OW3GJK | -- | -- |
| HDMI Connector Panel-Mount | 1 | [Amazon](https://a.co/d/hMF2q71) | B0CM386VJ3 | -- | -- |
| RJ45 Connector Panel-Mount | 1 | [Amazon](https://www.amazon.com/dp/B0C6PPZCV3) | B0C6PPZCV3 | -- | -- |
| Ethernet Extension Cable 1ft Female-to-Male | 1 | [Amazon](https://www.amazon.com/XANHAM-Ethernet-Extension-Extender-Connector/dp/B0CQ8F4CZX/) | B0CQ8F4CZX | -- | -- |
| 6-pole Receptacle Connector | 1 | [McMaster-Carr](https://www.mcmaster.com/8903T45/) | 8903T45 | -- | -- |
| 6-pole Plug Connector | 1 | [McMaster-Carr](https://www.mcmaster.com/8903T15/) | 8903T15 | -- | -- |
| 15" LCD Display | 1 | [Amazon](https://www.amazon.com/VSDISPLAY-1024X768-G150XGE-1000-Brightness-Controller/dp/B0BFRF126F) | B0BFRF126F | -- | -- |
| LCD1602 Display Module | 1 | [Amazon](https://www.amazon.com/SunFounder-Serial-Module-Display-Arduino/dp/B019K5X53O?th=1) | B019K5X53O | -- | -- |
| Right Angle USB A to USB B male connector | 1 | [Amazon](https://www.amazon.com/YCS-Basics-Black-Printer-Scanner/dp/B00B5HS7TI/) | B00B5HS7TI | -- | -- |

---

## Enclosure hardware

| Item | Qty | Manufacturer/Source | Part Number | Description | Notes |
|---|---|---|---|---|---|
| NANUK 930 Empty Case | 1 | [Nanuk Cases](https://nanukcases.ca/products/nanuk-930-empty) | 930S-000BK-0A0 | Main compute box enclosure | -- |
| ABS Mounting Plate for Junction Box | 1 | [Amazon](https://www.amazon.com/LeMotech-Junction-Mounting-Installation-Electrical/dp/B0CGCS2C4B?th=1) | B0CGCS2C4B | -- | -- |
| 3D Printed Attachments | TBD | TBD | TBD | -- | See [CAD]({{ site.baseurl }}/cad/) |
| Pull Handle | 2 | [McMaster-Carr](https://www.mcmaster.com/1568A64/) | 1568A64 | -- | -- |
| M5 Plastic-Head Thumb Screws | 1 (pack of 10) | [McMaster-Carr](https://www.mcmaster.com/96016A566-96016A237/) | 96016A566-96016A237 | -- | -- |

---

## Wiring

| Item | Qty | Manufacturer/Source | Part Number | Description | Notes |
|---|---|---|---|---|---|
| 16 AWG Wire | 1 roll | [Amazon](https://www.amazon.sg/NAOEVO-Conductors-Electrical-Extension-Automotive/dp/B0CP1SGHK7?th=1) | -- | Main power wiring | Red/black |
| 22 AWG Wire | 1 kit | [Amazon](https://www.amazon.com/Electric-Flexible-Silicone-different-Electronic/dp/B07G2JWYDW?th=1) | B07G2JWYDW | Signal wiring | -- |
| Heat Shrink Tubing | 1 kit | [Amazon](https://www.amazon.com/Eventronic-Shrink-Adhesive-Industrial-Heat-Shrink/dp/B0DK34NL18/) | B0DK34NL18 | -- | Multiple diameters |
| Expandable Braided Cable Sleeve Kit | 1 kit | [Amazon](https://www.amazon.com/Expandable-Sleeving-Automotive-Sheathing-Management/dp/B0F6YLMR18?th=1) | B0F6YLMR18 | Cable insulation | Multiple diameters |
| Lever Wire Electrical Connector Kit | 1 kit | [Amazon](https://www.amazon.com/dp/B07SFCCPZ6) | B07SFCCPZ6 | -- | -- |
| JST-HX Connectors | 1 kit | [Amazon](https://www.amazon.com/Taiss-560PCS-Connector-Adapter-Housing/dp/B09ZTWCZ3K/) | B09ZTWCZ3K | -- | -- |
| XT60 Connector | TBD | TBD | TBD | Battery connector | Optional |

---

## Fasteners

| Item | Qty | Manufacturer/Source | Part Number | Description | Notes |
|---|---|---|---|---|---|
| Metric Screw Assortment | 1 | [Amazon](https://www.amazon.com/dp/B0CBMMPPKF) | B0CBMMPPKF | -- | -- |
| Heat-set Insert (Metric) Assortment | 1 | [Amazon](https://www.amazon.com/FFVRVSS-M2-M3-Threaded-Inserts/dp/B0FWCF14RN) | B0FWCF14RN | -- | -- |
| M3 Standoff Spacers Kit | 1 kit | [Amazon](https://www.amazon.com/Csdtylh-Male-Female-Standoff-Stainless-Assortment/dp/B06Y5TJXY1/) | B06Y5TJXY1 | -- | -- |

---

## Miscellaneous

| Item | Qty | Manufacturer/Source | Part Number | Description | Notes |
|---|---|---|---|---|---|
| Two-Part Clear Epoxy | 1 | [Gorilla (Amazon)](https://www.amazon.com/Gorilla-Epoxy-Minute-Ounce-Syringe/dp/B001Z3C3AG?th=1) | B01M7VD07W | -- | -- |
| Loctite Super Glue Pro | 1 | [Loctite (Amazon)](https://www.amazon.com/Loctite-Liquid-Professional-Super-Glue/dp/B07VL6MP94?th=1) | B07VL6MP94 | -- | -- |
| Velcro 1in Straps | 1 | [Amazon](https://www.amazon.com/dp/B09QH2NVM1) | B09QH2NVM1 | -- | -- |
| Zip Ties | 1 | [Amazon](https://www.amazon.com/HAVE-ME-TD-Cable-Ties/dp/B08TVLYB3Q) | B08TVLYB3Q | -- | -- |
| Adhesive Zip Tie Mount | 1 | [Amazon](https://www.amazon.com/dp/B07M69LK65) | B07M69LK65 | -- | -- |

## Recommended spare components

The following spare components are recommended for field deployment:
- Extra buck converters
- Spare fuses
- Spare connectors
- Extra robot bodies
- Tape

## Notes

{: .note }
> Where possible:
>
> - use locking connectors
> - use waterproof feedthroughs for external connections
> - maintain consistent connector labeling

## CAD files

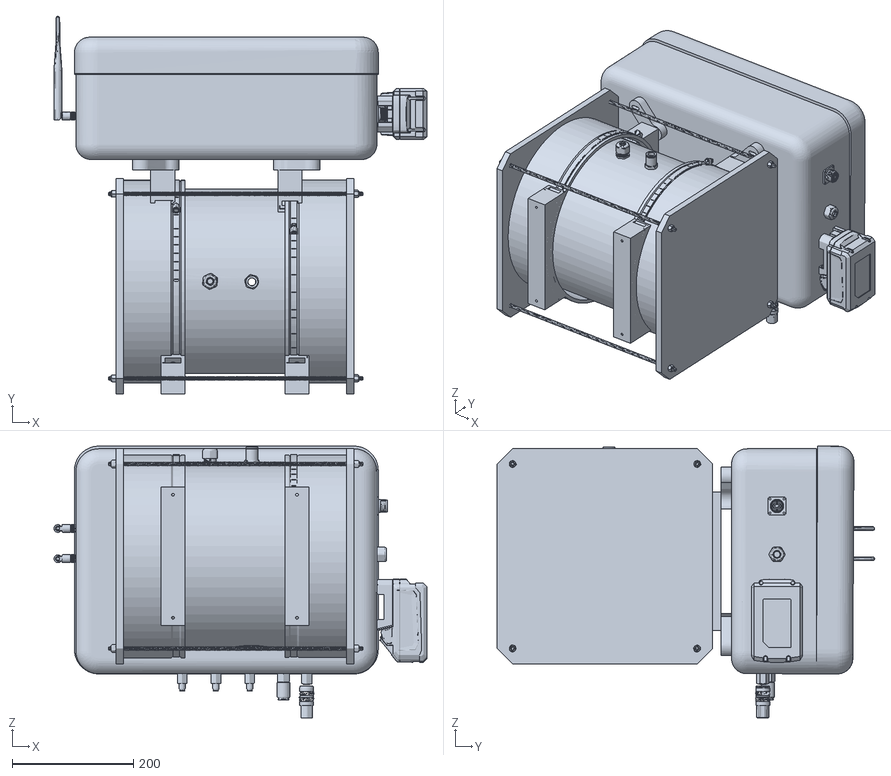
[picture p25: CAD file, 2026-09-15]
SPROUT_Design/CAD/SPROUT_assembly_exterior.stl
616.1 x 623.6 x 449.0

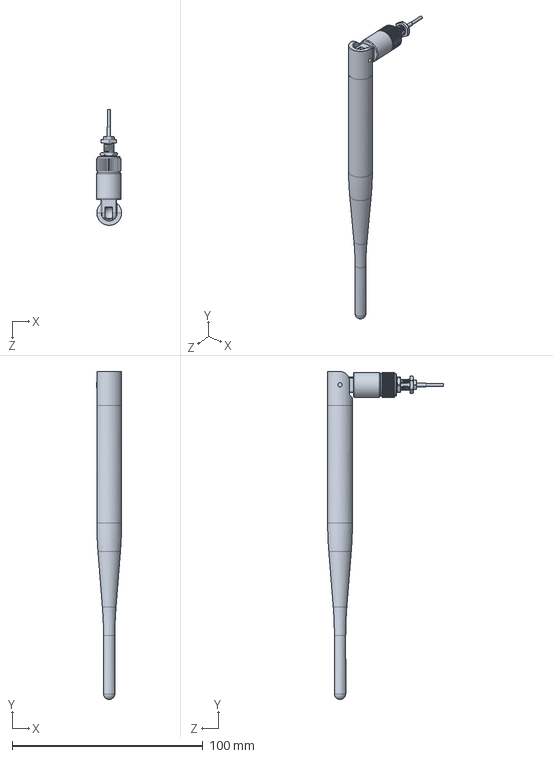
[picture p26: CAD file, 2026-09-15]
SPROUT_Design/CAD/Solidworks/compute_box/Antenna_assembly v4.SLDPRT
13.2 x 171.8 x 60.6 mm

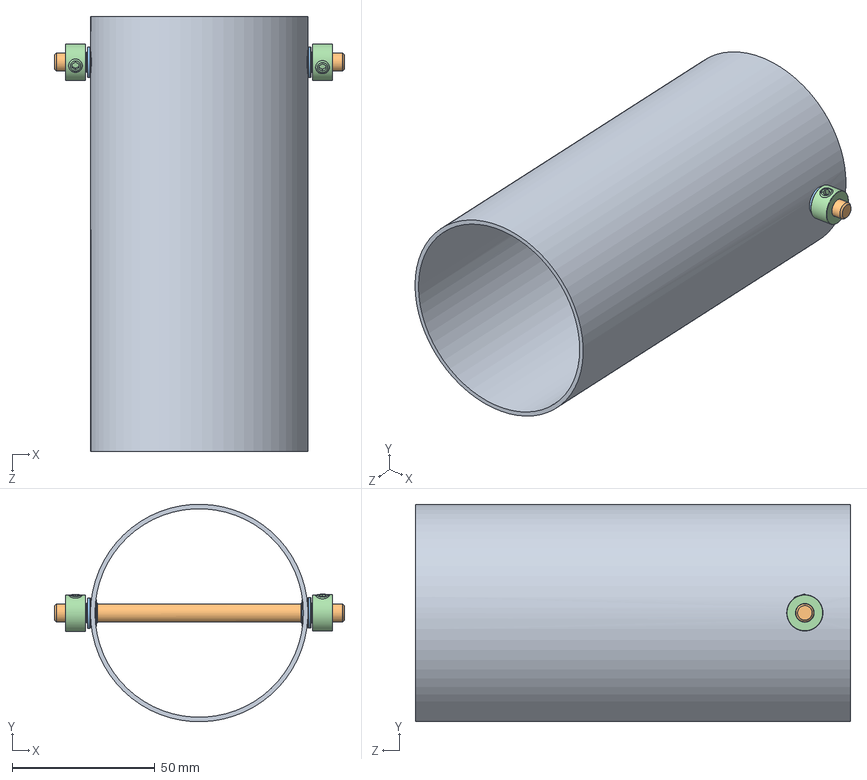
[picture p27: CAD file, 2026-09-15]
SPROUT_Design/CAD/Solidworks/sprout_base/outlet_subassembly.SLDASM
101.6 x 76.2 x 152.4 mm
8585K391_Impact-Resistant Polycarbonate Round Tube
1886K1_Rotary Shaft
57155K336_Stainless Steel Ball Bearing x 2
6432K12_Set Screw Shaft Collar x 2

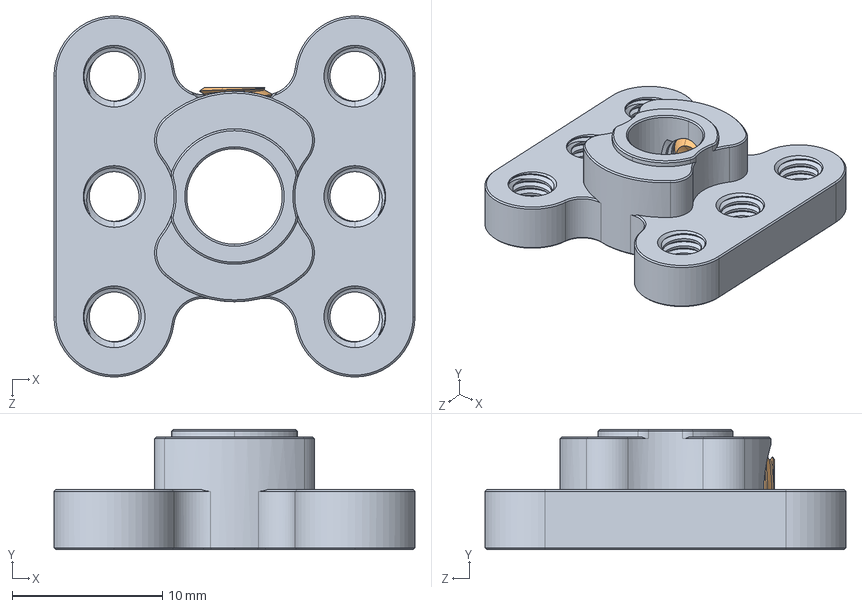
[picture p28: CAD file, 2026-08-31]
SPROUT_Design/CAD/Solidworks/sprout_base/1314-0016-0250 assembly.STEP
24.0 x 8.00 x 24.0 mm
2806-0005-0004_91390A117

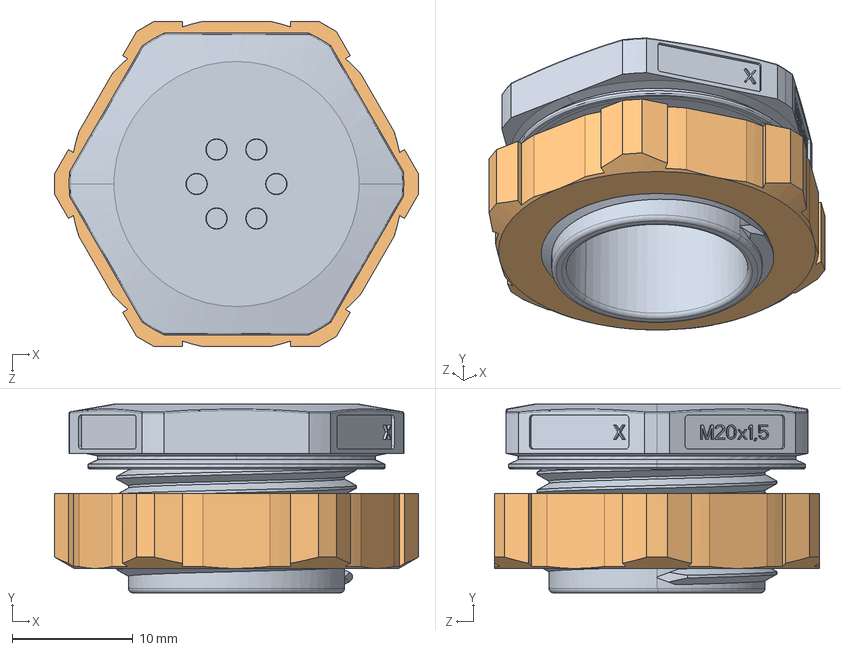
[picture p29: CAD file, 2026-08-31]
SPROUT_Design/CAD/Solidworks/compute_box/UA-006.SLDASM
30.2 x 15.6 x 27.0 mm
UA-006-BODY.STEP
NUT-M20-01.STEP

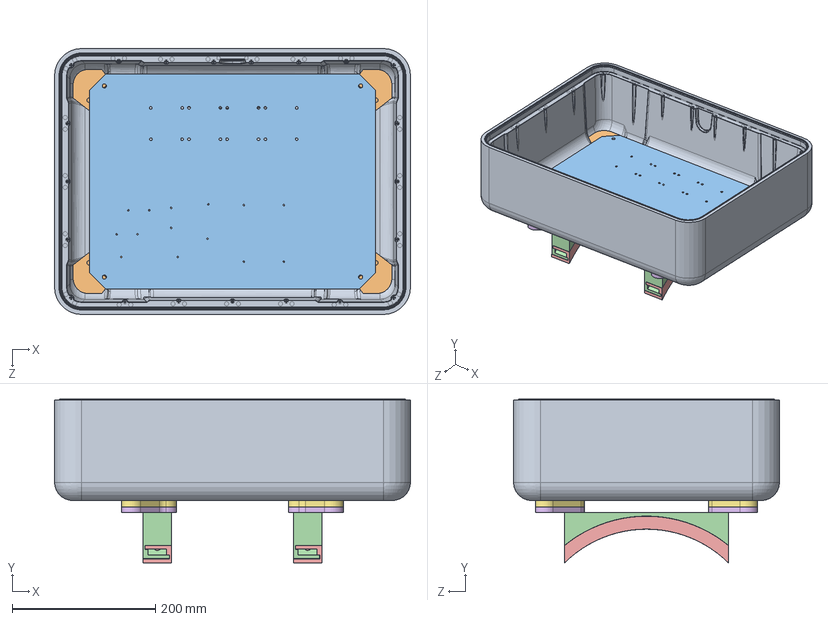
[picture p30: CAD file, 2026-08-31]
SPROUT_Design/CAD/Solidworks/compute_box/case_assembly.SLDASM
497.4 x 228.7 x 371.7 mm
CASE_930_R1_Btm_INNER_SURFACE
plate_interface x 4
bottom_panel
feet_part_2 x 2
feet_part_1 x 2
feet_rail_simplified x 2
base_bottom_insert_simplified x 2

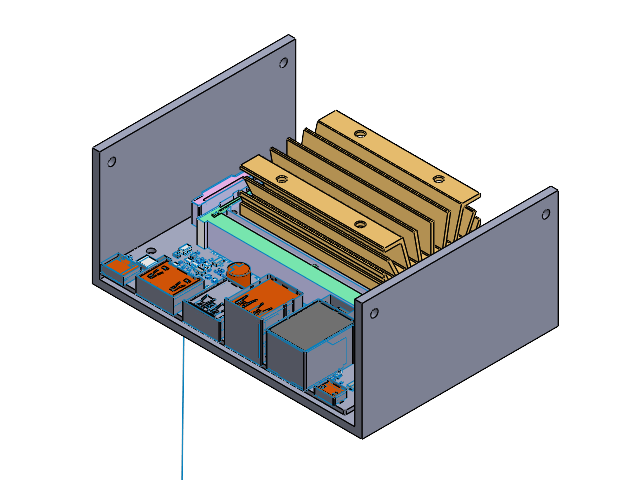
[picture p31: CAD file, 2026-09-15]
SPROUT_Design/CAD/Solidworks/compute_box/jetson_subassembly.SLDASM
jetson_base
jetson_computer

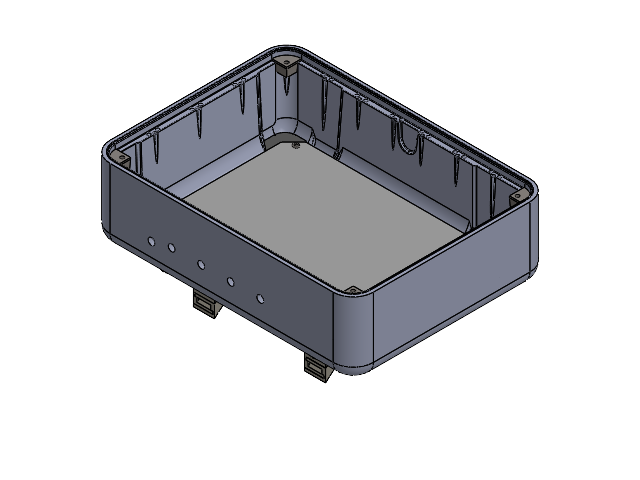
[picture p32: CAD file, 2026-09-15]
SPROUT_Design/CAD/Solidworks/compute_box/case.SLDASM
CASE_930_R1_Btm_INNER_SURFACE
plate_interface x 4
bottom_panel
feet_part_2 x 2
feet_part_1 x 2
feet_rail_simplified x 2
base_bottom_insert_simplified x 2
92000A318_Passivated 18-8 Stainless Steel Pan Head Phillips Screws x 4
plate_corner_holder x 4

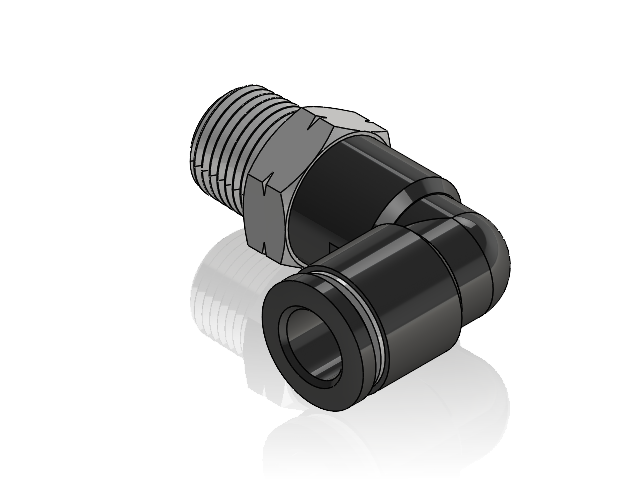
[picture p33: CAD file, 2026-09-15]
SPROUT_Design/CAD/Solidworks/compute_box/1_8 NPT - 1_4 Inch Push to Connect Elbow Fitting.SLDASM
Body003.step
Cut.step
Body022.step
Body023.step

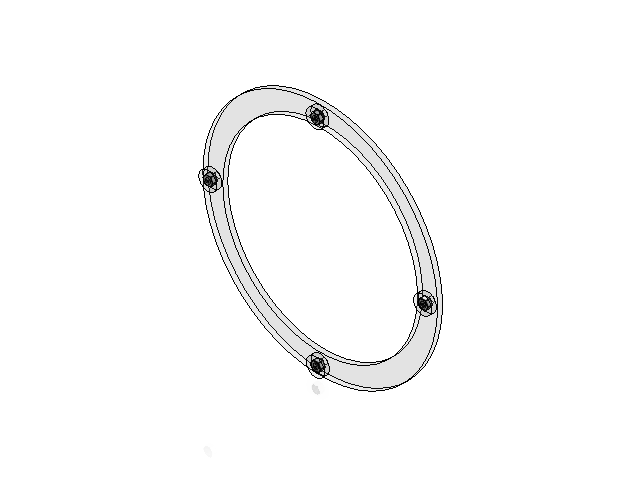
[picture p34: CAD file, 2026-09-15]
SPROUT_Design/CAD/Solidworks/sprout_base/mounting_plate_subassembly.SLDASM
Holder Plate Large
HexHolder x 4
95462A029_Medium-Strength Steel Hex Nut x 4

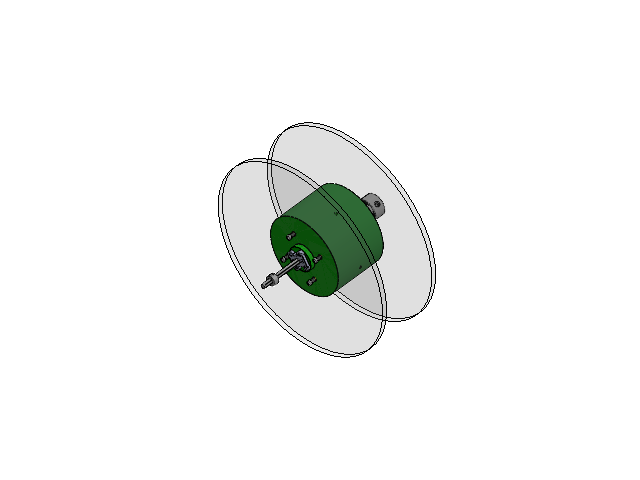
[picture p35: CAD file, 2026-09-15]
SPROUT_Design/CAD/Solidworks/sprout_base/spool_subassembly.SLDASM
SpoolGuideLarge x 2
SpoolBig
8632T139_D-Profile Rotary Shaft
6432K12_Set Screw Shaft Collar
6408K111_Flexible Shaft Coupling Iron Hub x 2
6408K84_18000 rpm Buna-N Rubber Spider for 1-5-64 OD Flexible Shaft Coupling Iron Hub
94180A331_Tapered Heat-Set Inserts for Plastic x 8
91290A121_Alloy Steel Socket Head Screw x 8
1314-0016-0250.STEP
2806-0005-0004_91390A117.STEP

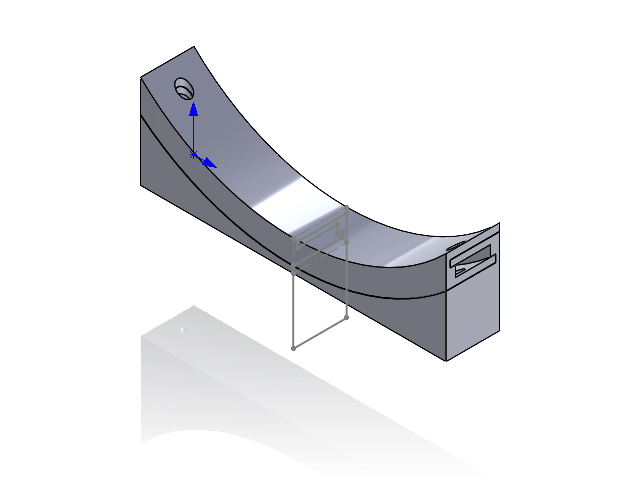
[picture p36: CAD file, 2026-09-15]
SPROUT_Design/CAD/Solidworks/compute_box/feet_assembly.SLDASM
feet_part_2
feet_part_1

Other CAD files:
SPROUT_Design/CAD/STEP/1314-0016-0250 assembly.STEP.STEP
SPROUT_Design/CAD/STEP/SPROUT_assembly.STEP
SPROUT_Design/CAD/STEP/mounting_plate_subassembly.STEP
SPROUT_Design/CAD/STEP/Assem1^outlet_subassembly.STEP
SPROUT_Design/CAD/STEP/jetson_subassembly.STEP
SPROUT_Design/CAD/STEP/outlet_subassembly.STEP
SPROUT_Design/CAD/STEP/1314-0016-0250.STEP.STEP
SPROUT_Design/CAD/STEP/1568A64_Threaded-Hole Round Pull Handle_1568A64.STEP
SPROUT_Design/CAD/STEP/1860N13_Wet-Location HDMI Connector_1860N13.STEP
SPROUT_Design/CAD/STEP/1886K1_Rotary Shaft_1886K1.STEP
SPROUT_Design/CAD/STEP/1_8 NPT - 1_4 Inch Push to Connect Elbow Fitting.STEP
SPROUT_Design/CAD/STEP/1_8 NPT - 1_4 Inch Push to Connect Elbow Fitting.step.STEP
SPROUT_Design/CAD/STEP/2806-0005-0004_91390A117.STEP.STEP
SPROUT_Design/CAD/STEP/3V210-08NC SOLENOID VALVE.STEP
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

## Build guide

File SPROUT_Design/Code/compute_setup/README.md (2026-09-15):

# SPROUT Compute



Reference system architecture for fully realized system

## Setup

Set up the [Jetson](./jetson/README.md).

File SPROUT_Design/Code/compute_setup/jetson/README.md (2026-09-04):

# Jetson Nano Bootstrap

Helpful guides on how to install the ROS2-ready system on the Jetson Orin Nano. The following instructions utilize an SSD to flash the Nano image. We recommend at least a 1 TB SSD installed into the NVMe SSD slot on the bottom of the Jetson. Before proceeding.

## Flashing Jetpack to the Device

Follow the [official instructions available from NVIDIA](https://www.jetson-ai-lab.com/initial_setup_jon.html). We recommend using the instructions in the section in *Alternative method : SDK Manager* section.

We suggest using JetPack 6.1.X. The host computer which performs the flashing of the Jetson will need to be an Ubuntu 20/22 device.

After flashing, boot the device, and proceed to setup a user name and password. We recommend naming the device `jetson`. For ease of use, we recommend setting the device to auto-login. Do not install the Chromium browser.

## Increasing Performance

Follow the [instructions](https://developer.nvidia.com/embedded/learn/get-started-jetson-orin-nano-devkit#maxn) from NVIDIA to switch the device to MAXN SUPER mode, which will operate the device with up to 25 W of power.

## Fixing Chromium

By default, the default source for the Chromium web browser is broken. Use the following commands to get a working version.

```bash
sudo apt update
sudo apt install flatpak
flatpak remote-add --if-not-exists flathub https://dl.flathub.org/repo/flathub.flatpakrepo
flatpak install flathub org.chromium.Chromium
```

## Installing ROS2

```bash
sudo apt update
sudo apt install -y curl gnupg2 lsb-release build-essential
sudo curl -sSL https://raw.githubusercontent.com/ros/rosdistro/master/ros.key -o /usr/share/keyrings/ros-archive-keyring.gpg
echo "deb [signed-by=/usr/share/keyrings/ros-archive-keyring.gpg] http://packages.ros.org/ros2/ubuntu $(lsb_release -cs) main" | \
  sudo tee /etc/apt/sources.list.d/ros2.list > /dev/null
sudo apt update
sudo apt install -y ros-humble-desktop
source /opt/ros/humble/setup.bash
echo "source /opt/ros/humble/setup.bash" >> ~/.bashrc
source ~/.bashrc
```

### Install Visual Studio Code
```bash
cd ~/Downloads
wget https://update.code.visualstudio.com/1.77.3/linux-deb-arm64/stable
sudo dpkg -i stable
```

## Installing Necessary System Packages

```bash
sudo apt install -y \
  python3-colcon-common-extensions \
  python3-rosdep \
  python3-vcstool \
  python3-pip \
  git \
  nano \
  htop \
  nvidia-cuda \
  nvidia-tensorrt \
  nvidia-opencv \
  terminator \
  libhidapi-dev
```

JTOP is the recommended system monitoring tool for processor/GPU performance. It must be installed with `sudo`.
`sudo pip3 install -U jetson-stats`

### Creating a Colcon Workspace

```bash
mkdir -p ~/ws/src
cd ~/ws
colcon build
```
We also add a utility command to assist with rebuilding the repo:
`
echo "alias build_ros='cd ~/ws && colcon build && source install/setup.bash'" >> ~/.bashrc
`

## Switch Desktop to XFCE

By default the desktop on the Jetson consumes around 1 GB of RAM during idle operation. We can improve that by switching to a lightweight desktop.

`sudo apt-get install xfce4`

After installing, log out, then when you log back in select the gear icon near the login button to change the desktop session to xfce. This change will persist the next time you log in.

## Configure Ports on the joystick controller and Arduino

Follow this dedicated [guide](./usb_rules.md) to setup the various required and optional device connections.

## Configure ROS Workspace
Move into the ROS workspace, clone necessary packages, and build repo.

```bash
cd ~/ws/src
git clone git@github.com:SPROUT-MITLL/sprout_ros.git # Install SPROUT ROS
git clone -b ros2 git@github.com:SPROUT-MITLL/ds5_ros.git # SPROUT fork of DS5 driver
cd ~/ws
colcon build
source ../devel/setup.bash
```
## Install Arduino IDE

These instructions will download an app image containing the Arduino IDE for an ARM64 device.
```bash
cd Downloads
wget https://github.com/koendv/arduino-ide-raspberrypi/releases/download/2.2.0/Linux_arm64_app_image.zip
unzip Linux_arm64_app_image.zip
chmod +x arduino-ide_2.2.1_Linux_arm64.AppImage # Make the app image executable
./arduino-ide_2.2.1_Linux_arm64.AppImage # Run the app image
```
Allow the application to initialize and install necessary packages upon first system boot. The [Encoder](https://docs.arduino.cc/libraries/encoder/) package is the only non-default package required to compile the sketch.

## Flash Arduino with Code

Connect the Arduino to the Jetson via USB cable.

Open the Arduino sketch: `~/ws/src/sprout_ros/arduino/vine_control/vine_control/vine_control_uno_rev3`

Make sure the IDE is connected to the Arduino Uno on `/dev/ttyACM0`. Verify and upload the sketch to the device.

Once `Upload Finished` is displayed, the device is ready to use!

## Adding the Screen

We need to enable the Jetson Nano to communicate with the LCD screen over GPIO. First run the following commands to enable software access.

```bash
sudo apt-get update
sudo pip3 install Jetson.GPIO
sudo groupadd -f -r gpio
sudo usermod -a -G gpio <<USER_NAME>>
```

Power off the Jetson, and unplug from the power source. Use the wiring guide below to connect the LCD screen to the Jetson using jumper wires.

Jetson Nano Screen Screen Wiring Guide

## Start ROS Nodes Automatically

If you named your user something other than `jetson` during the setup, modify the home directory under the `ExecStart` command in `sprout_ros.service`.
```
sudo cp ~/ws/src/sprout_ros/resource/sprout_ros.service /etc/systemd/system/
sudo systemctl enable sprout_ros.service
```

In order to allow USB devices access on boot, we will need to give permission to unprivileged users.

```bash
cd /etc/udev/rules.d/
sudo touch local.rules
sudo nano local.rules
```
Add the following line into the file.

`echo "ACTION=="add", KERNEL=="dialout", MODE="0666"`

Reboot the system: `sudo reboot now`

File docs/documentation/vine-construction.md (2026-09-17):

---
layout: default
title: Vine Construction
parent: Documentation
nav_order: 5
---

# Vine Robot Body Fabrication
{: .no_toc }

<style>
  .center-img {
    display: block;
    margin-left: auto;
    margin-right: auto;
    width: 50%;
  }
</style>

This page covers building the vine robot body itself — the soft,
pneumatically-actuated "vine" that everts from the base — as opposed to the
[compute box]({{ site.baseurl }}/documentation/) that drives and powers it.

## Table of contents
{: .no_toc .text-delta }

- TOC
{:toc}

---

## Overview

The general fabrication workflow is:

1. Prepare materials, equipment, and workspace
2. Cut fabric
3. Mark fabric with stencil
4. Form and seal the robot body
5. Install pneumatic fittings
6. Inspect and test the completed body

Detailed instructions for each stage are provided below.

---

## Materials, equipment, and tools

### Materials

| Item | Qty | Manufacturer/Source | Part Number / Specification | Notes |
|---|---:|---|---|---|
| Heat-Sealable TPU Coated Nylon Fabric | At least 4 meters (width by length) | [Adventure Xpert](https://www.adventurexpert.com/product/30d-nylon-66-tpu-one-sided/) | --- | --- |
| Painter's Tape (1 in) | 1 roll | [Scotch Blue](https://www.amazon.com/ScotchBlue-Original-Multi-Surface-Painters-2090-24NC/dp/B00004Z4CP/) | --- | --- |
| Magic Tape (1 in) | 1 roll | [Scotch](https://www.amazon.com/Scotch-Magic-Tape-Inch-Count/dp/B01C5IHGJW/) | --- | --- |
| Double-Sided Red Tape (Heat Resistant) | 1 roll | [Amazon](https://www.amazon.com/BAOFALI-Resistant-AdhesivesPerfect-Microbeads-Scrapbooking/dp/B0CHP8RTSV/) | --- | --- |
| Permanent Marker, Fine Point | 1 | [Sharpie](https://www.amazon.com/Sharpie-37161PP-Permanent-Markers-Resists/dp/B00144862U/) | --- | --- |
| PP/PVC Sheet | 1 | [Amazon](https://www.amazon.com/Plastic-Colored-Folders-Letter-Straight/dp/B09J1KNW1M/) | --- | Used a plastic folder, but could be anything that can be perforated or laser cut |
| Push-to-Connect, Through-Wall Connectors | 3 | [Amazon](https://a.co/d/0crJj5wt) | --- | --- |

See the [main BOM]({{ site.baseurl }}/documentation/bom.html) for compute box hardware.

### Fabrication equipment and tools

| Item | Notes |
|---|---|
| [Precision Pick](https://www.amazon.com/ROTATION-4-Piece-Precision-Automotive-Aluminum/dp/B0CHGJHV77/) | --- |
| [6" x 24" Sewing & Quilting Ruler with Gridlines](https://www.amazon.com/gp/aw/d/B0C8BMVL93/) | --- |
| Yard Stick / Straight Edge | --- |
| X-Acto Knife | --- |
| Scissors | --- |
| [Foot-Operated Impulse Sealer](https://www.uline.com/Product/Detail/H-89/Poly-Bag-Sealers/Foot-Operated-Impulse-Sealer-18) | ULINE H-89 |

{: .note }
> The foot-operated heat sealer H-89 has limited space in the back between the sealing edge and the stand post. This makes it difficult to handle fabric while sealing, especially when making a long vine robot (10ft+). For an enhanced model that facilitates the process in a roll-to-roll manufacturing style, see the [H-1256 model](https://www.uline.com/Product/Detail/H-1256/Poly-Bag-Sealers/Foot-Operated-Impulse-Sealer-with-Cutter-18).

<!-- ### Provided files

| File / Folder | Description |
|---|---|
| TODO | Robot body cutting pattern / template |
| TODO | Reference drawings and dimensions | -->

---

## Workspace and equipment preparation

Before beginning fabrication:

1. Clean the work surface and remove debris that could damage the fabric.
2. Gather the required materials, tools, and fixtures.
3. Verify that all fabrication equipment is operating correctly, especially the impulse sealer.

   {: .warning }
   > Overheating of the heating element can ruin hours of work in a couple of seconds (and overheating errors are hard to fix!). Underheating, on the other hand, can result in a robot that bursts at low actuation pressures.

4. Adjust the impulse sealer to the correct sealing time using the knob. This adjustment is critical to a good seal, and the correct value will depend heavily on the fabric — some TPU coatings need more heat to seal than others.
5. Practice sealing a few times with a remnant piece of fabric to get used to the process.

---

# Fabrication procedure

## Step 1: Fabric preparation

### Stencil preparation

Here we show how to make a stencil so the marking process is less tedious and less prone to human error. The stencil shown in these steps is very basic (a piece of plastic with holes in it!), but a more precise version could be made by laser cutting a stencil out of thin PVC or acrylic sheet.

1. Grab a plastic folder and unfold it a couple of times so it lies flat. Mark the desired distance from one edge, and cut it to the desired stencil width.
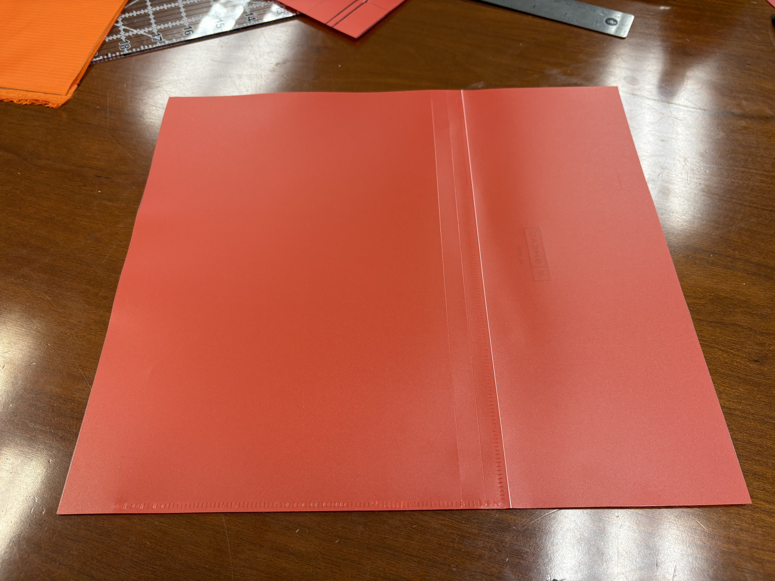
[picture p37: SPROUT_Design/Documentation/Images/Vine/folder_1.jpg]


2. Use the permanent marker to mark the stencil according to the provided template.
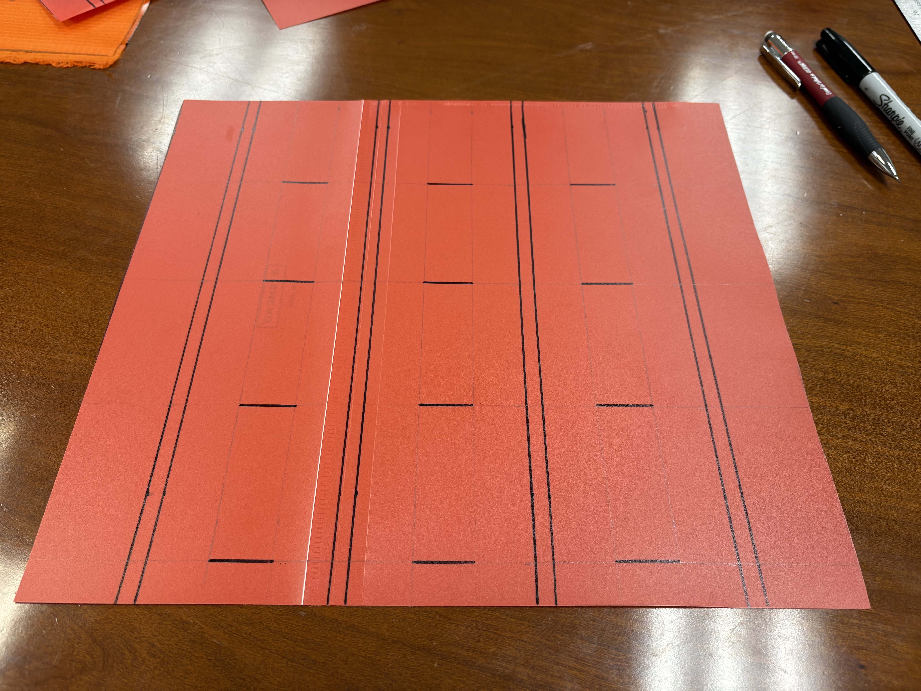
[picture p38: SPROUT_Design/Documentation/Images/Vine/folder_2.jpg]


3. Make holes at the edges of each mark line using the precision pick.
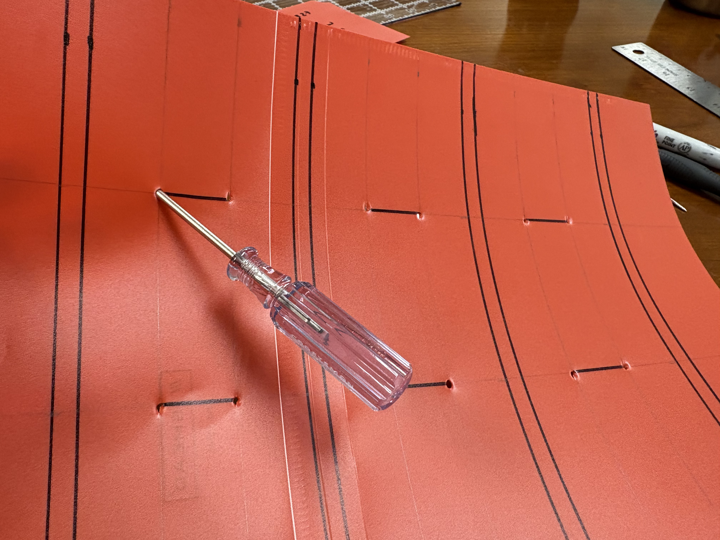
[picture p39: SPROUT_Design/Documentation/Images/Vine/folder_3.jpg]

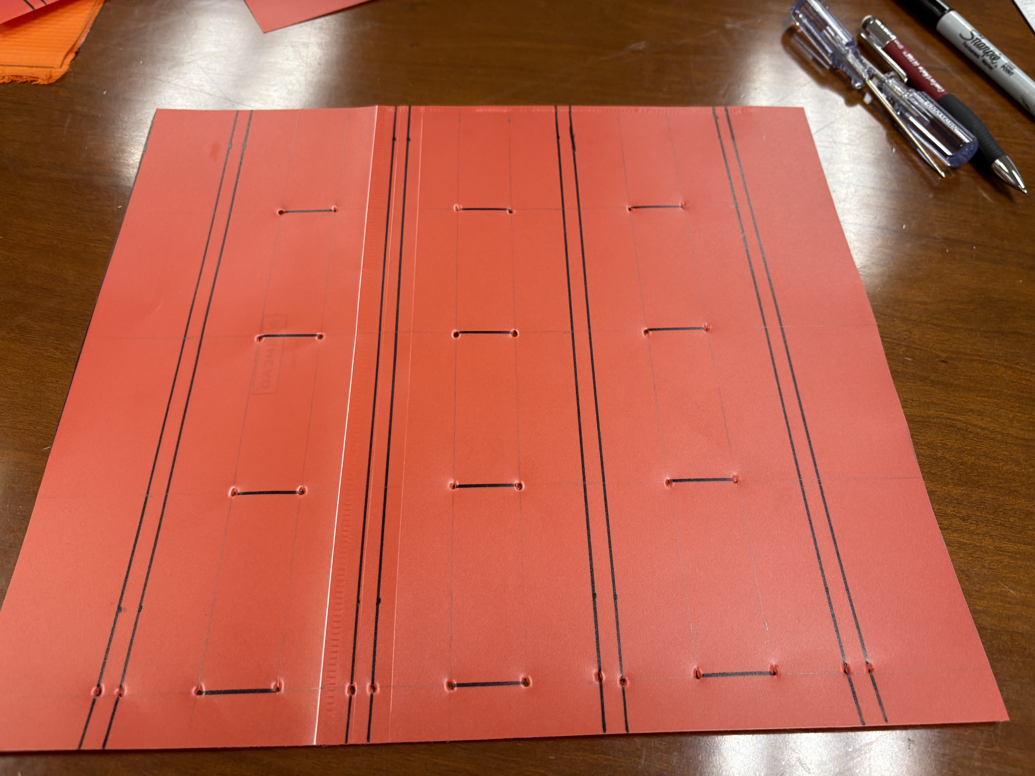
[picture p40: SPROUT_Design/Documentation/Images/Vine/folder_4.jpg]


### Material cutting and marking

1. Cut a piece of fabric around 27in wide (and as long as the desired robot length).
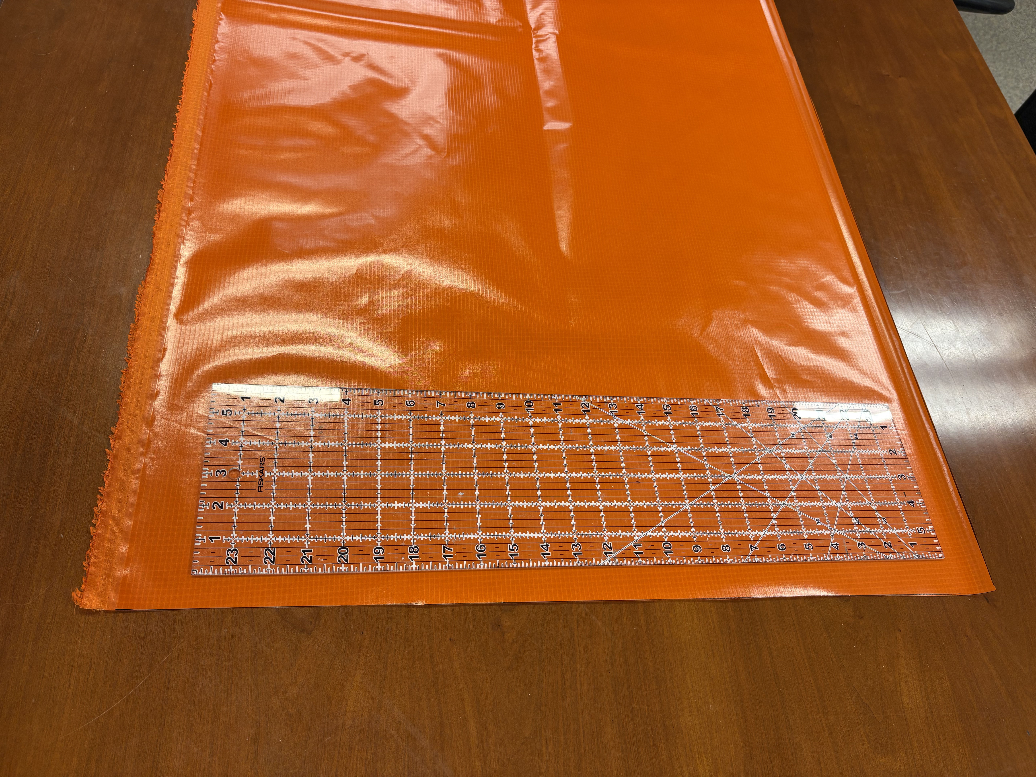
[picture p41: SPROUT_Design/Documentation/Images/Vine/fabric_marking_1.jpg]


2. Lay the fabric flat on a surface with the TPU side down and place the stencil in one corner. Use the marker to mark each of the holes in the stencil, including the outer edges and the ends of each line in the stencil.
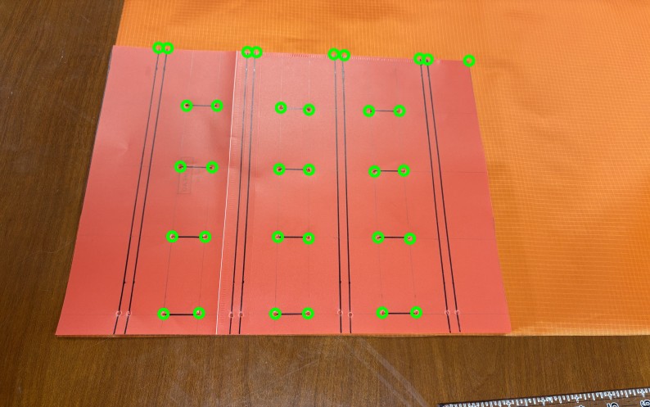
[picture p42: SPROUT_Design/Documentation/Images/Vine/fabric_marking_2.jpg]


3. Move the stencil forward down the length of the fabric and align it with the previously made markings.
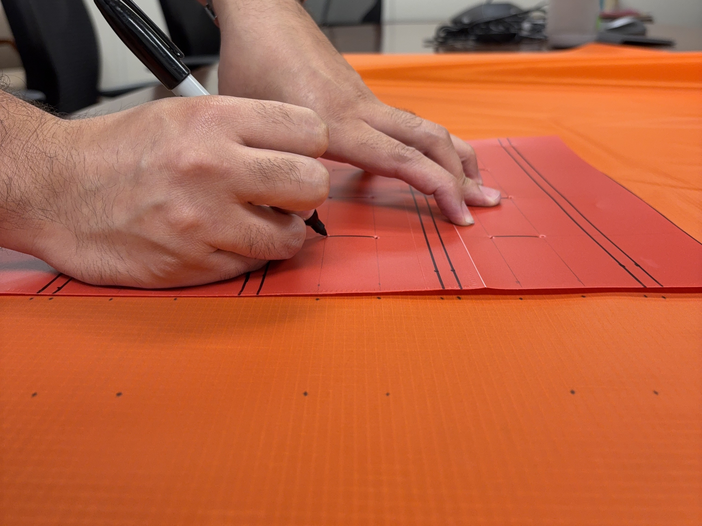
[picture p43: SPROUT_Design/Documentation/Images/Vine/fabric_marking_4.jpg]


4. Continue until the whole length of the fabric is marked.
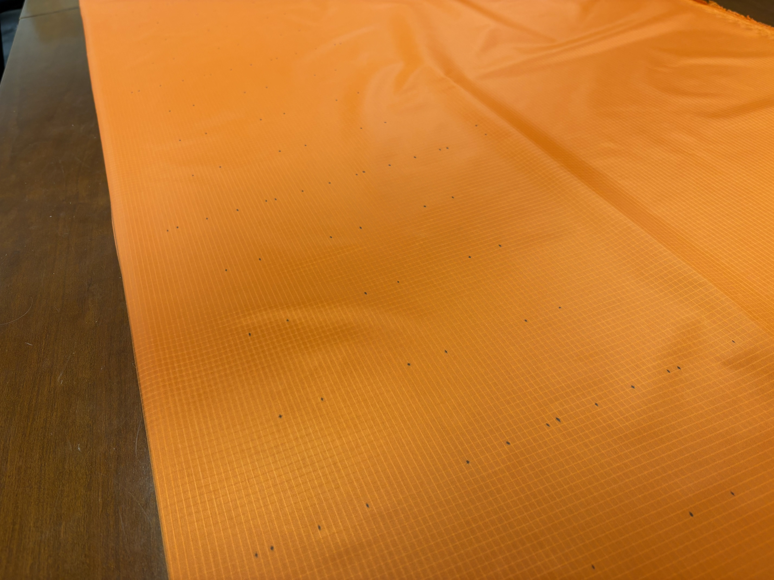
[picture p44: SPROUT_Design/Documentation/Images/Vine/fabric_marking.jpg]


5. Fold the fabric in half (width-wise) with the TPU side inside. Keep the marked side facing up.
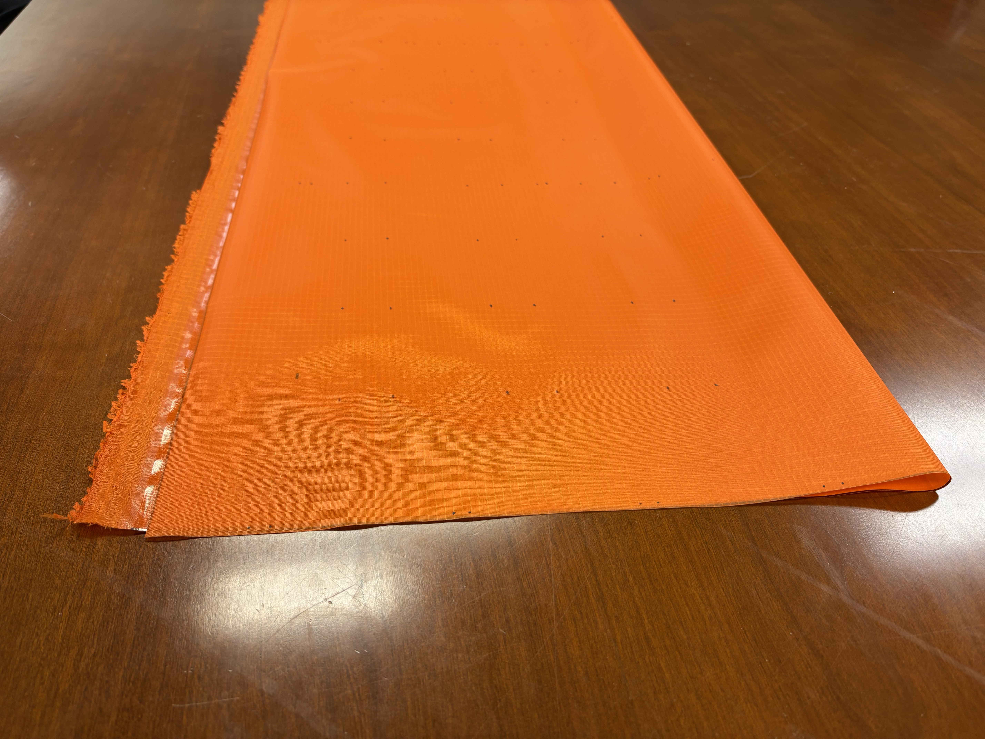
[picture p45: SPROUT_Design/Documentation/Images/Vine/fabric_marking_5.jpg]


6. (Optional) Use the yard stick or straight edge to mark the lines shown in the stencil. The end product should look as below.
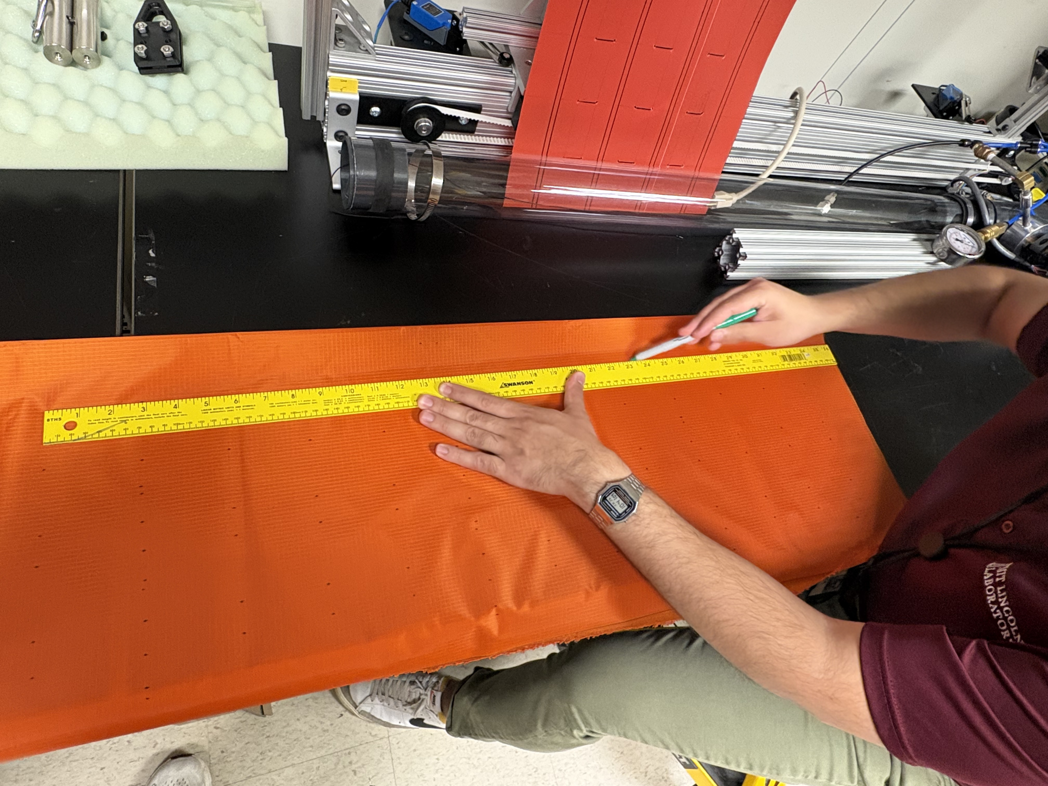
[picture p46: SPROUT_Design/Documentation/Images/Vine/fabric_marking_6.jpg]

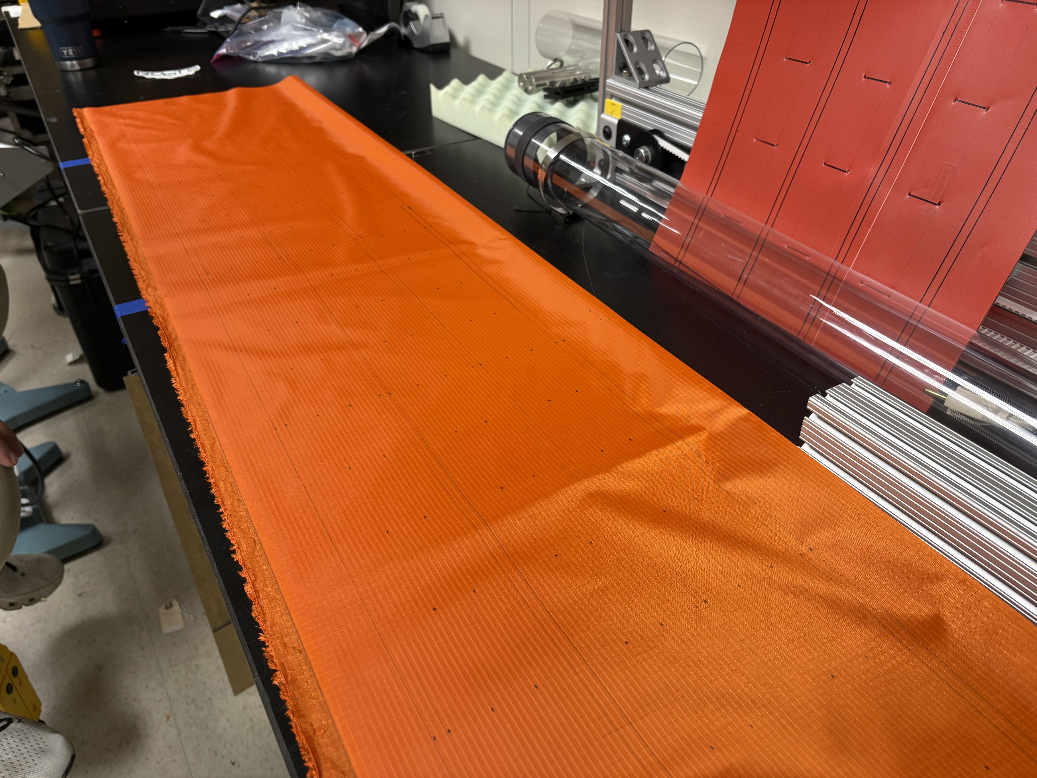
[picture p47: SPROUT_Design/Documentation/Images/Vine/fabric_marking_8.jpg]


---

## Step 2: Heat sealing fabric

### Lengthwise heat seals

1. With the fabric folded, grab the edges carefully to keep them aligned. Place the fabric in the impulse sealer, holding it aligned with the lengthwise mark closest to the edge, and press the sealer.
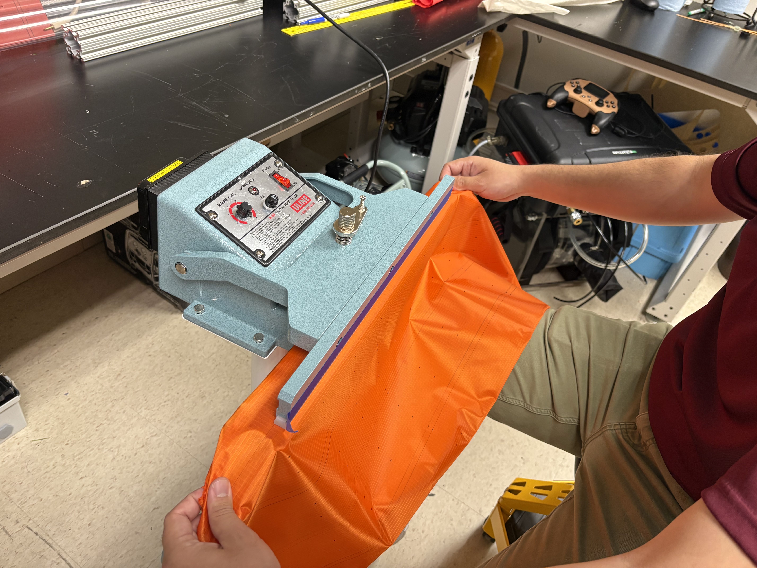
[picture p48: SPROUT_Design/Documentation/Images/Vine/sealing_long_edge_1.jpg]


2. Repeat the process for the remaining lengthwise marks (4 total).
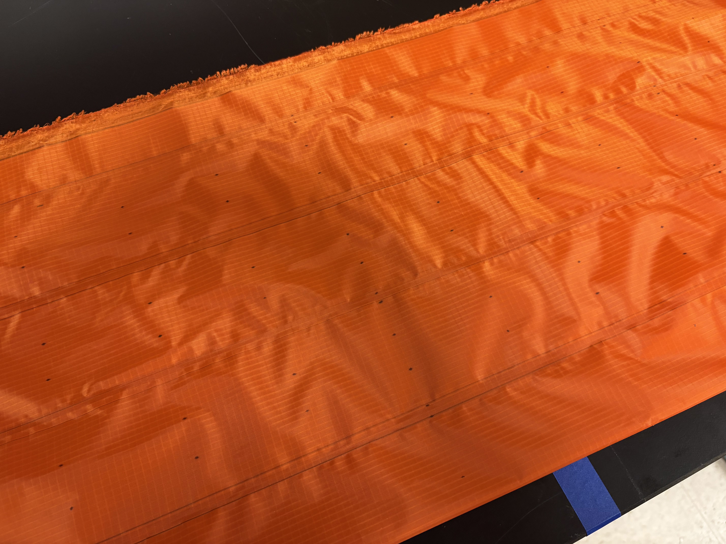
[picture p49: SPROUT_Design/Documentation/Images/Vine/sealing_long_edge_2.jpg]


3. One edge of the fabric (width-wise) should be closed due to the fold. Open this end with scissors so it has two flaps like the other end.

### Pouch motor line heat seals

1. Stick a piece of heat-resistant red tape along the length of the impulse sealer. Use the stencil to mark the width of the pouch motor lines.

2. Use the X-Acto knife to cut the tape at the marked locations, so the spots where a heat seal is desired are tape-free.
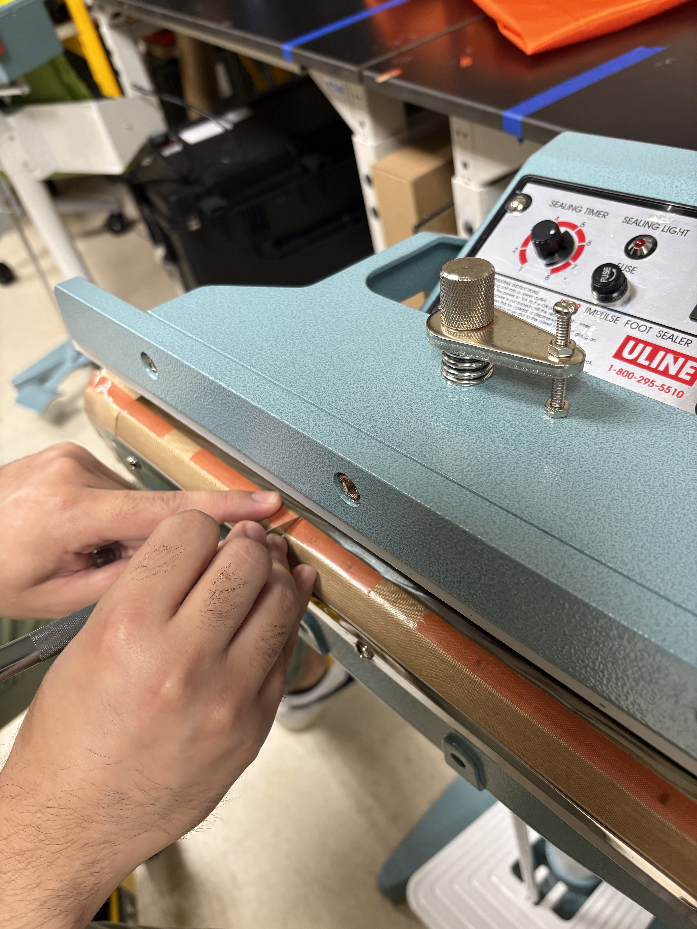
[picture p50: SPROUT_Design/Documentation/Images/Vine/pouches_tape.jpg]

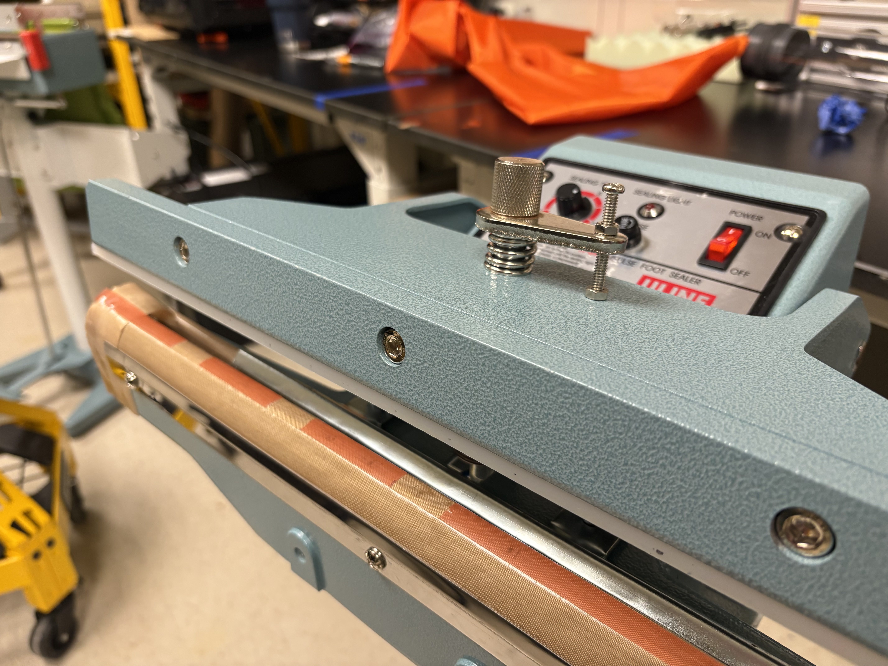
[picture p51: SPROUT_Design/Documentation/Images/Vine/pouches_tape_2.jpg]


3. Grab the fabric width-wise and hold it tight at both edges. Line up the fabric so the pouch motor line markings align with the tape on the sealer, and press the sealer.
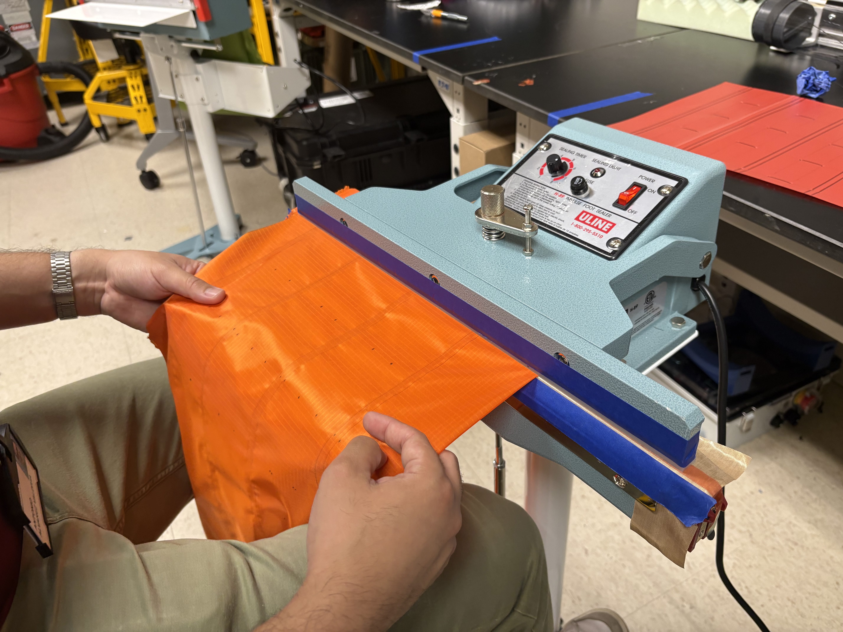
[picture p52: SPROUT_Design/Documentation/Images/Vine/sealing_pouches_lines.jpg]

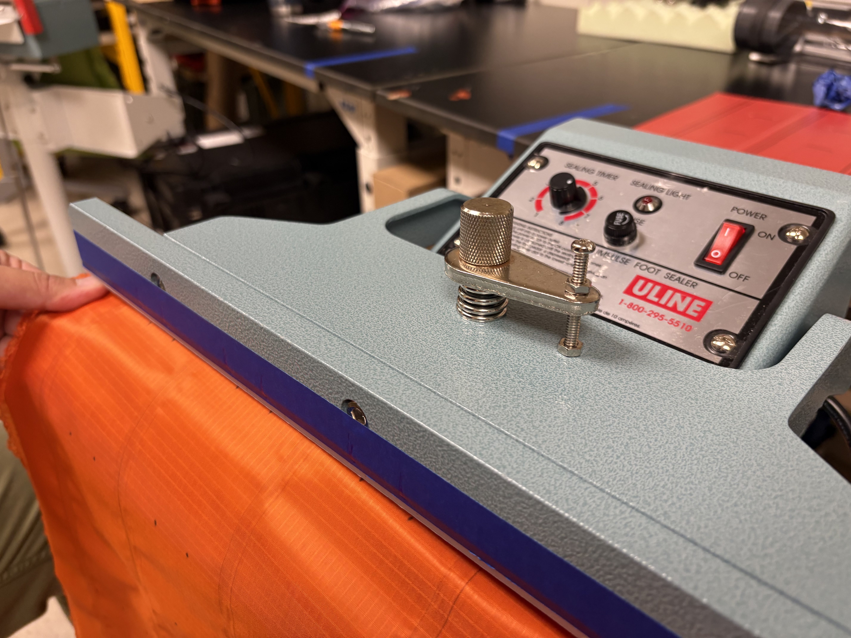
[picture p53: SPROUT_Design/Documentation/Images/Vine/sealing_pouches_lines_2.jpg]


   {: .note }
   > Placing a piece of painter's tape on the top edge of the sealer clamp and marking it with the stencil can help with alignment during pouch motor sealing.

4. Continue sealing the pouch motor lines along the whole length of the robot.
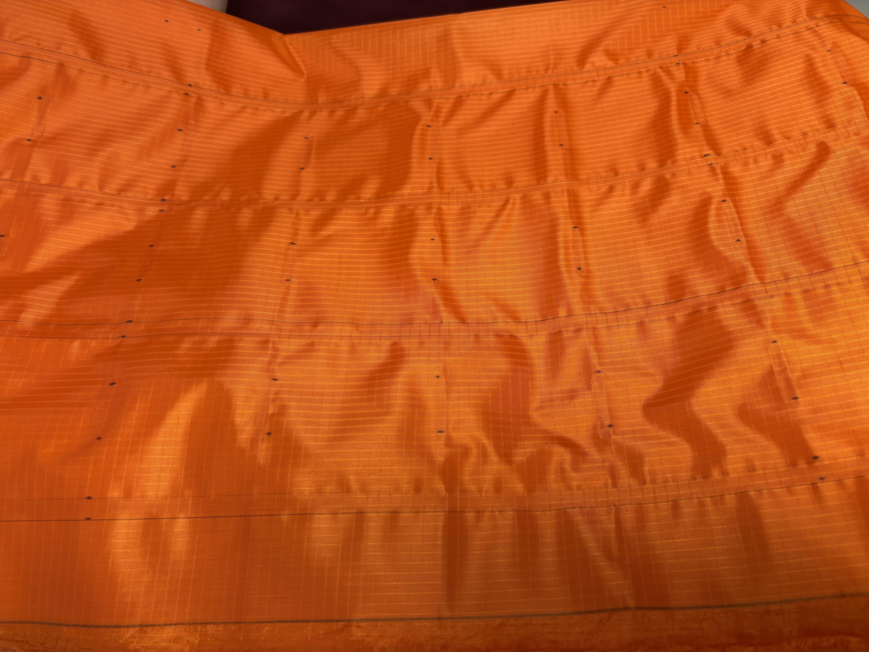
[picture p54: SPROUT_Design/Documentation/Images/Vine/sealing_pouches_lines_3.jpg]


   {: .important }
   > Leave one end of the robot with approximately 6in of fabric without pouch motor seals. This end will have the push-to-connect adapters used to actuate each pouch motor line.

5. Once done, remove the tape markings from the sealer.

6. Inspect the pouch motor seals for weak seams or unintended bonding in regions protected by heat-resistant tape. Some residual bonding may occur where heat spreads beyond the intended seal area; these bonds are typically weak and can be separated by gently pinching and pulling the fabric apart.

### Join the longitudinal seam

1. Lay the fabric flat. On each side, fold the top flap completely inward, lay it flat, and tape it down with the magic tape.
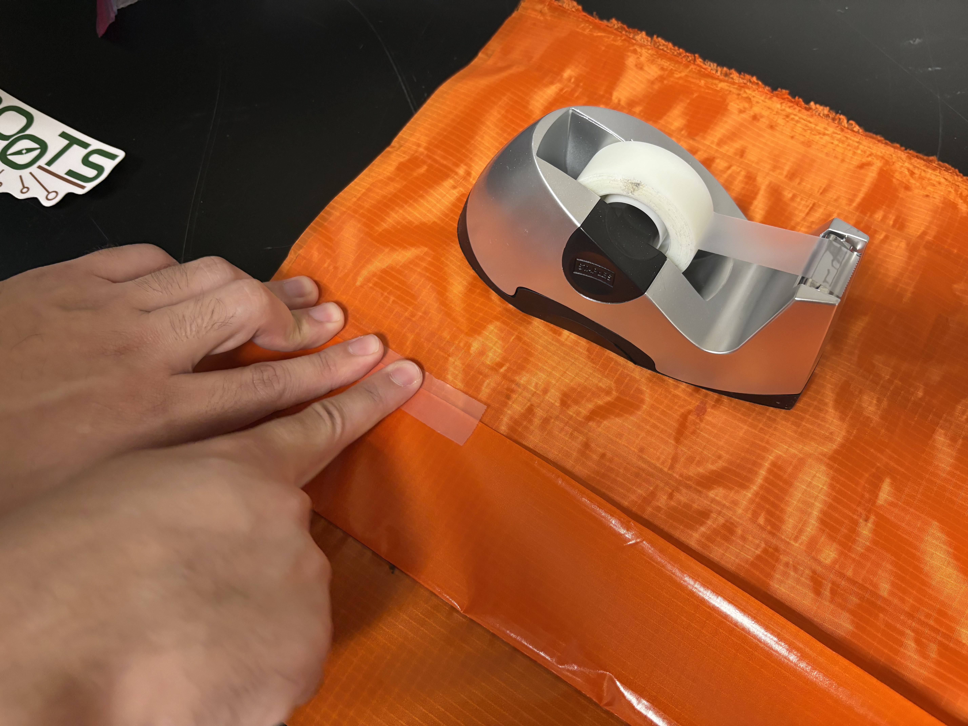
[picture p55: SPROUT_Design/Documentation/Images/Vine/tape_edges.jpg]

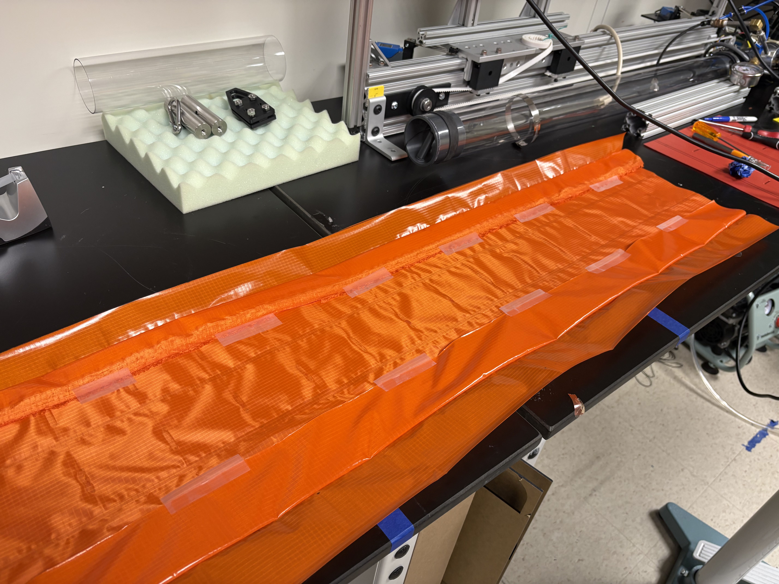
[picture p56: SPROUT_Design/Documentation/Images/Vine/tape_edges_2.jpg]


2. The exposed TPU on each edge will be joined with the sealer. On one end of the robot fabric, grab the edges, fold the fabric, and line the edges up so the exposed TPU sides face each other.
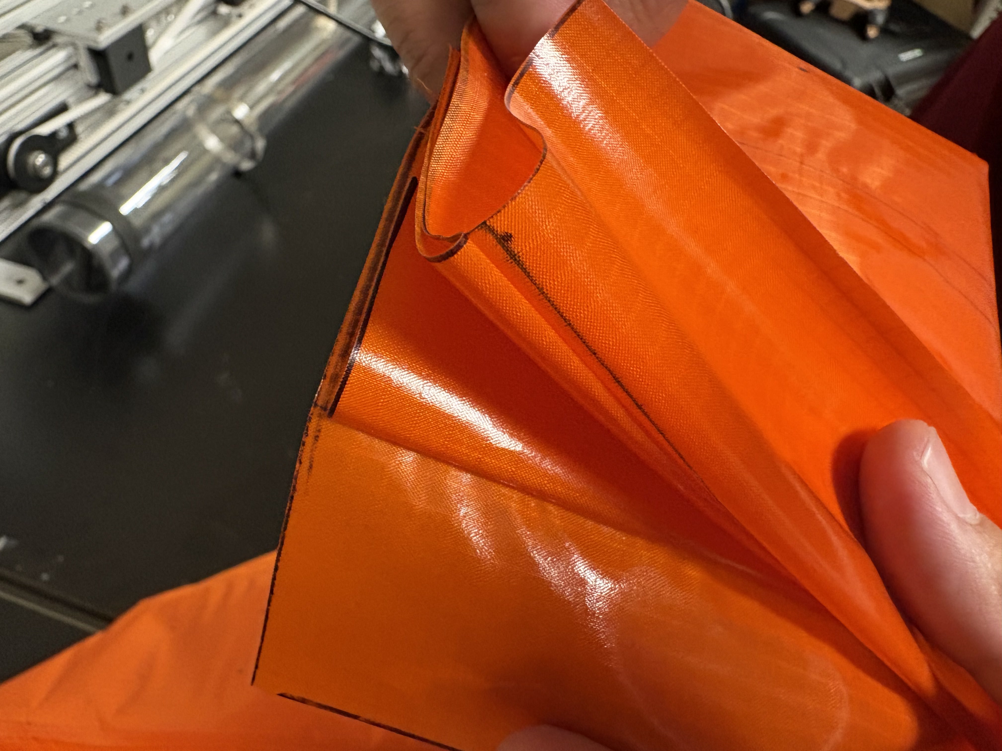
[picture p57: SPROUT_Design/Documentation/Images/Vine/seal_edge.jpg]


3. Carefully line up the fabric in the sealer lengthwise, just above the outermost marking, and press the sealer.
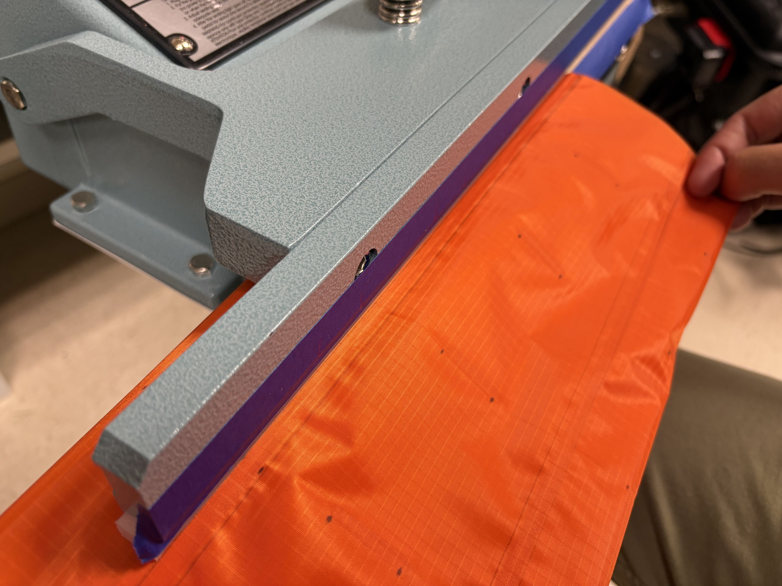
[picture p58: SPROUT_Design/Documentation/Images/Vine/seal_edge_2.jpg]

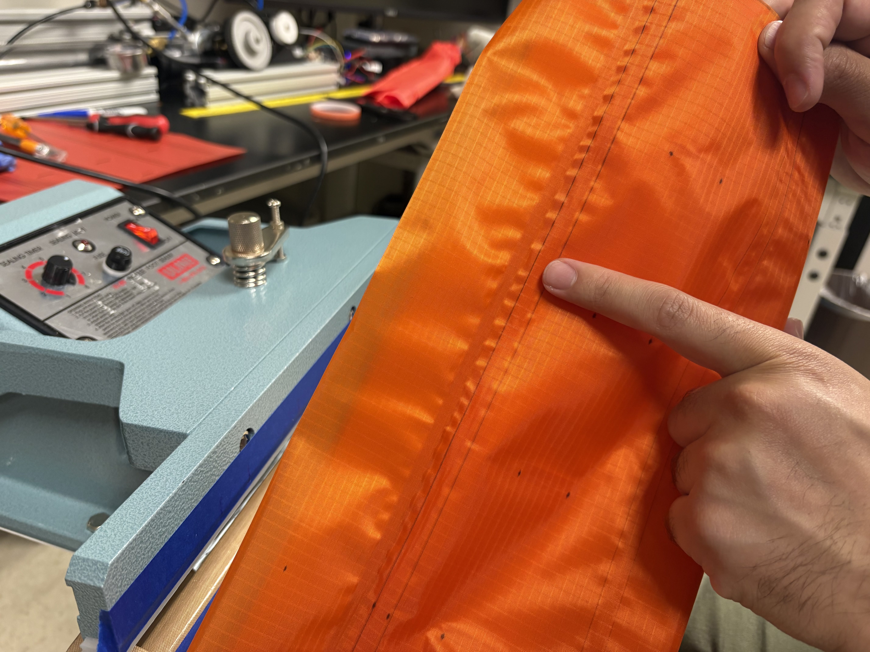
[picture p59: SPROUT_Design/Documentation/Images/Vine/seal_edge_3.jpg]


4. Repeating this process a couple more times above the previous sealed line can reinforce the body by adding more sealed surface area lengthwise.

5. Turn the robot inside out so the taped flaps are on the outside, then remove the tape. The two exposed TPU flaps should now be facing each other.
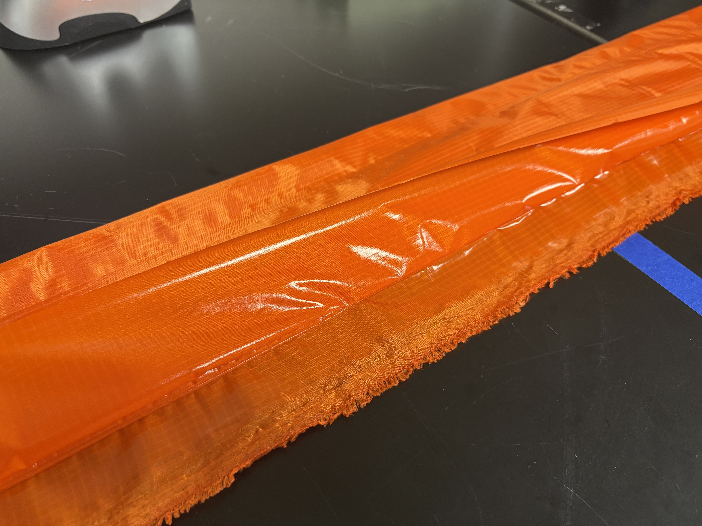
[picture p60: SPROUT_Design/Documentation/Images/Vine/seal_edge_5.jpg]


6. Seal these flaps together along the whole length. The robot now has two sealed edges for extra reinforcement — one inside and one outside.
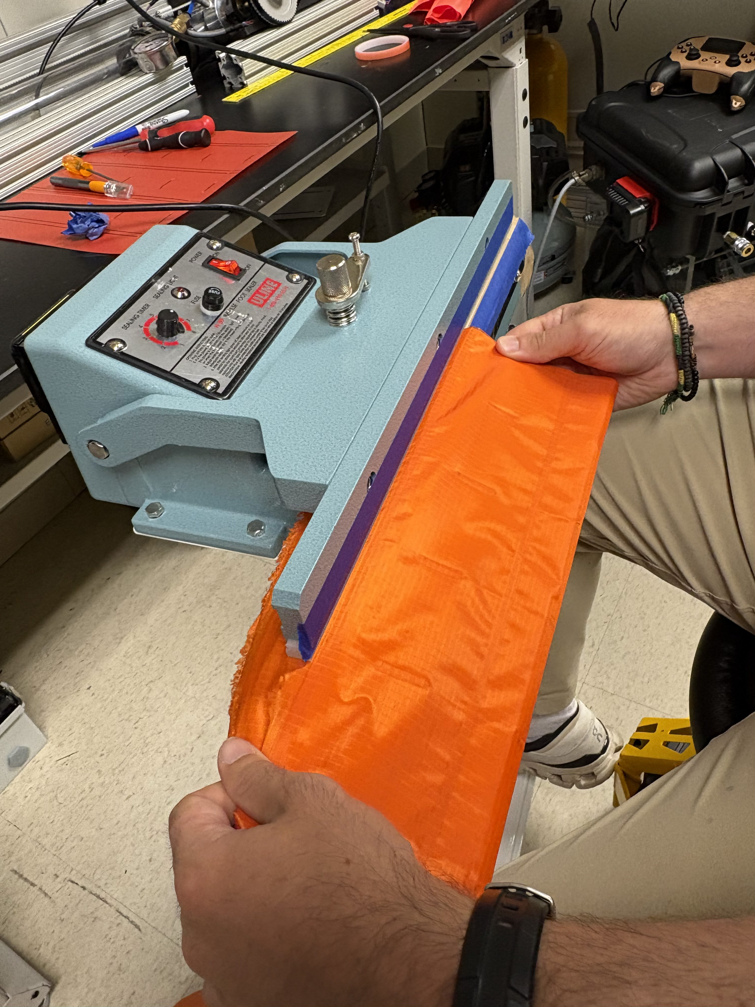
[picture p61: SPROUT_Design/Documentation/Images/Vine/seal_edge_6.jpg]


7. At this point, it is a good idea to inspect the seams and reinforce them if needed.

---

## Step 3: Pneumatic fittings

1. A push-to-connect fitting will be added to each of the pouch motor lines.
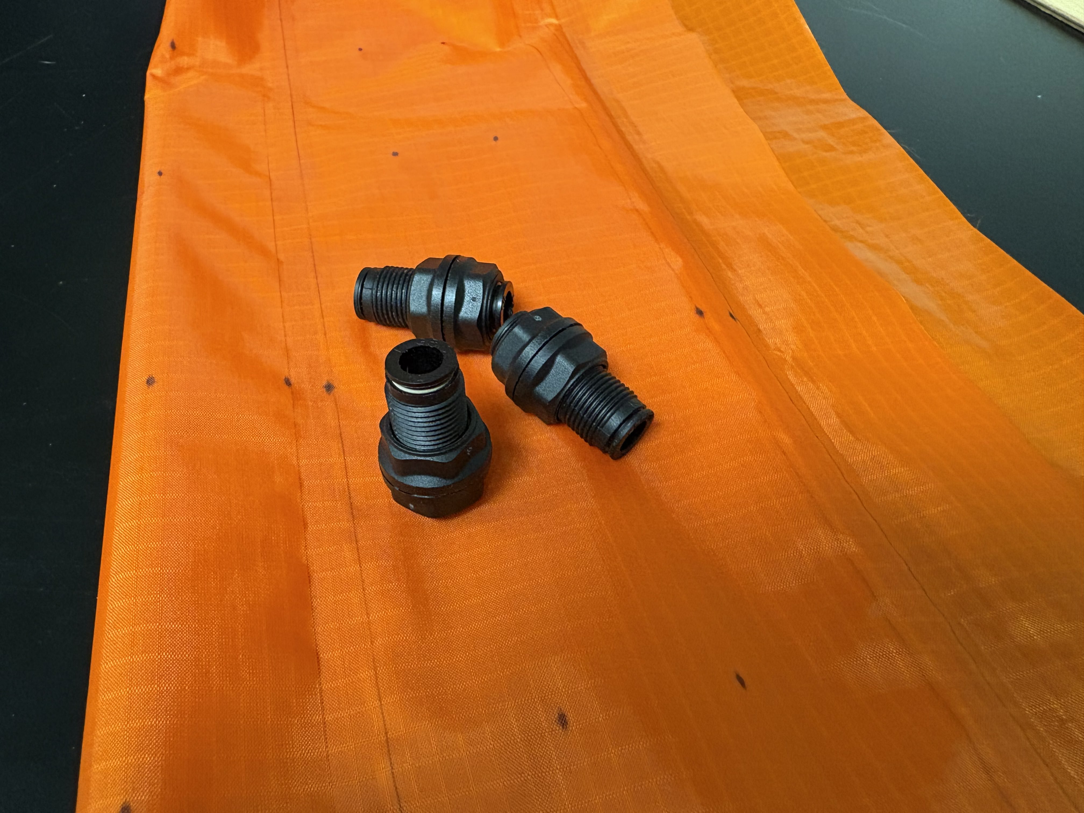
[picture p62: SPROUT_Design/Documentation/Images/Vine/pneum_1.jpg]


2. Make a horizontal line 6-7cm from the edge on one of the pouch lines.
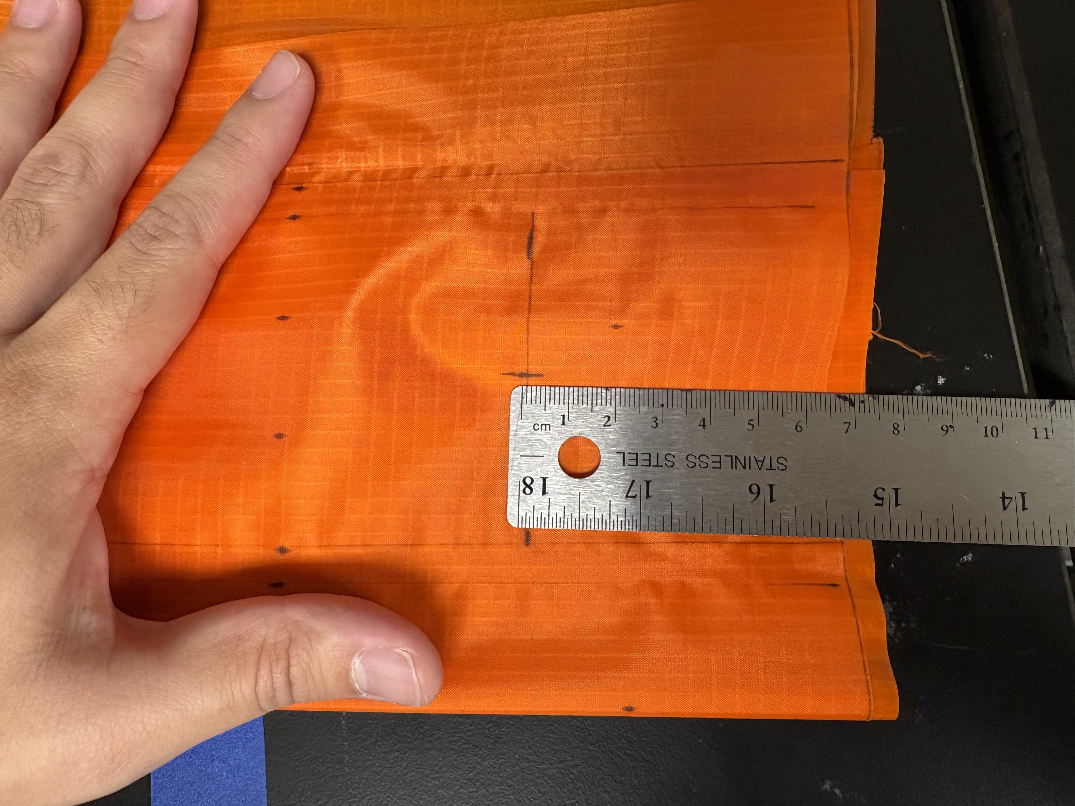
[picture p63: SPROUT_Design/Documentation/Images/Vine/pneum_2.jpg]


3. Grab a connector and use it to mark a circle right in the middle of the line.
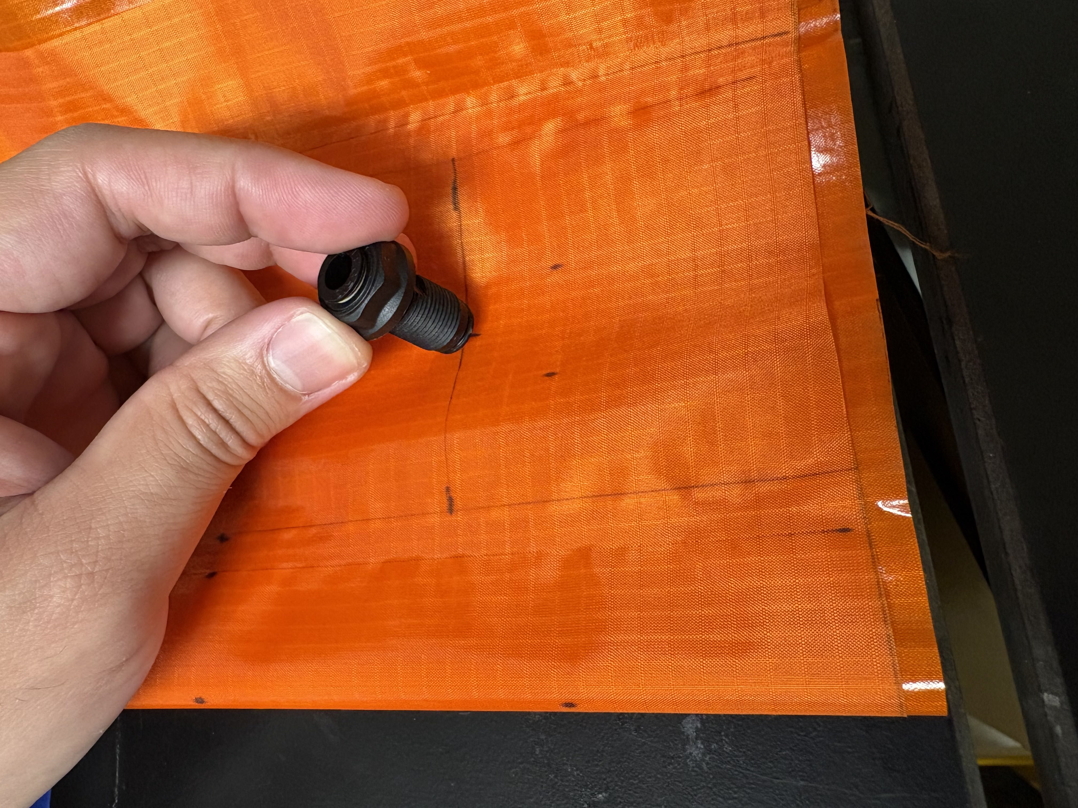
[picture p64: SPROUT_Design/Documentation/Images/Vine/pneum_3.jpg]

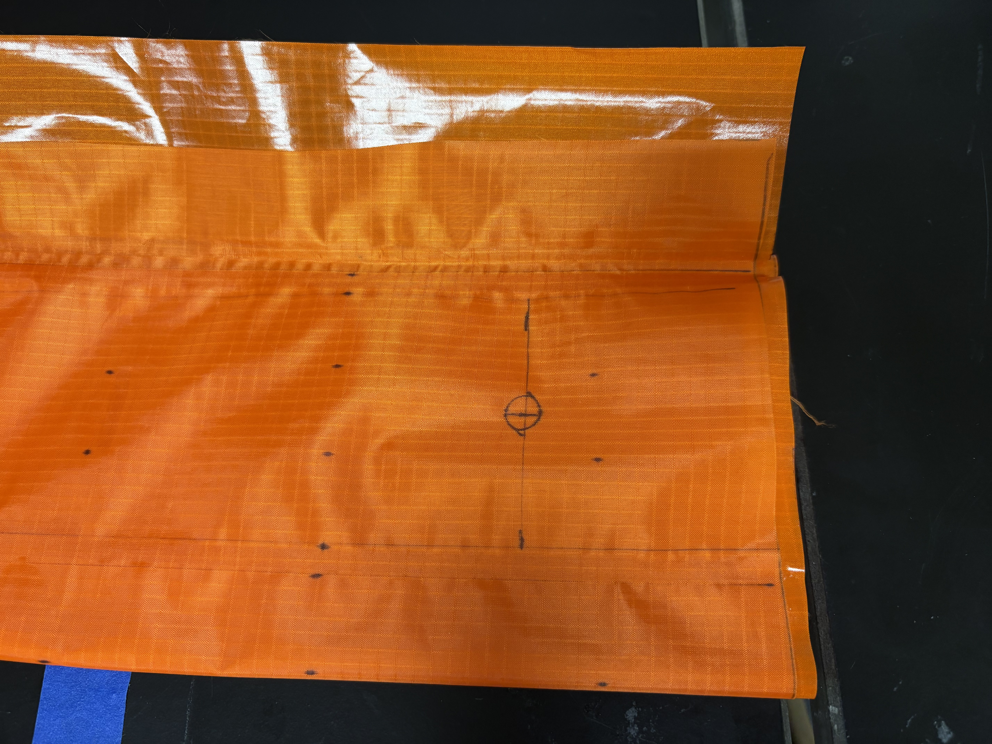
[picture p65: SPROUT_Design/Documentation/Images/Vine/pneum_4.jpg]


4. Repeat steps 2 and 3 on each pouch motor line.

5. Insert a piece of rubber, wood, or another slender, thick material inside a pouch motor line, then use the X-Acto knife to cut an opening in the marked circle. The slender insert prevents cutting through the inner fabric layers.
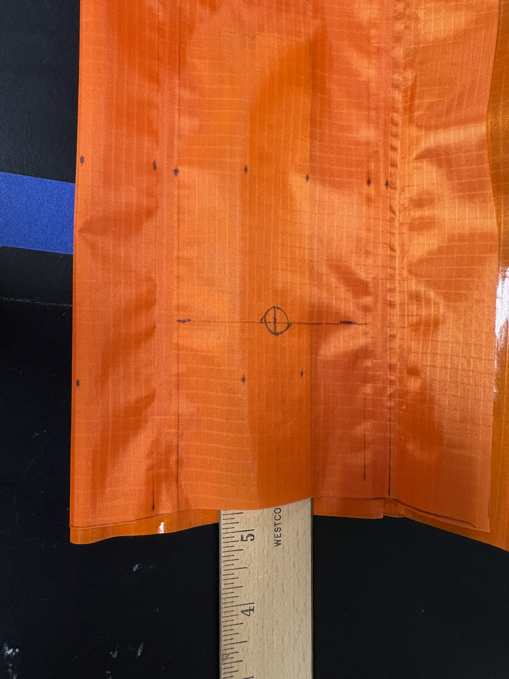
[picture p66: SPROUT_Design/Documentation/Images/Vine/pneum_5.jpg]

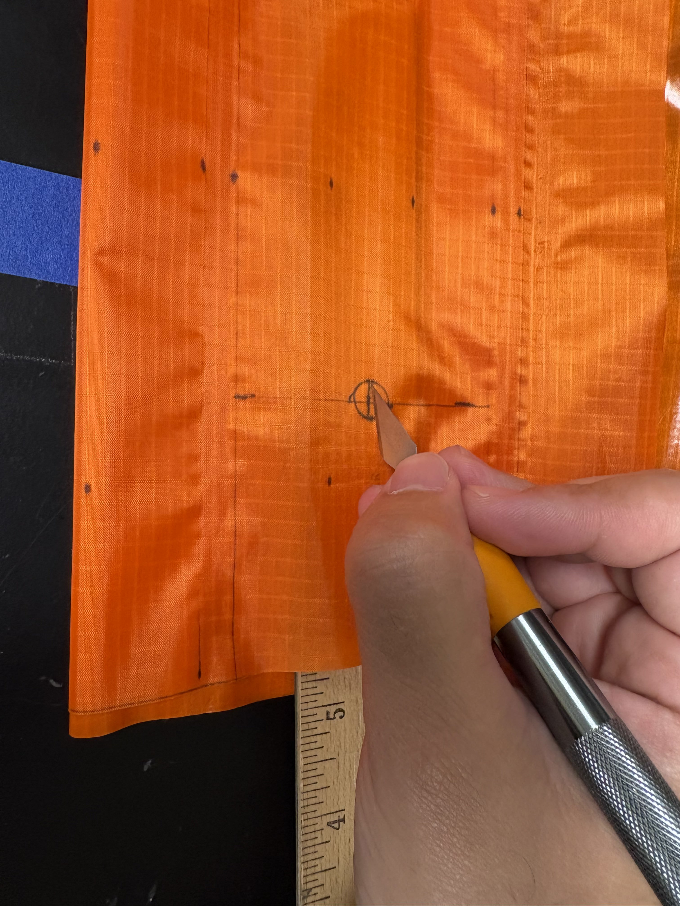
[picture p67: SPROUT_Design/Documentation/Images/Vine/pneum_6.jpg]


6. Repeat step 5 for all three pouch motor lines.

7. To install the pneumatic adapters, slide them inside each pouch motor line, push them through the cut holes, and secure them with the provided nut.
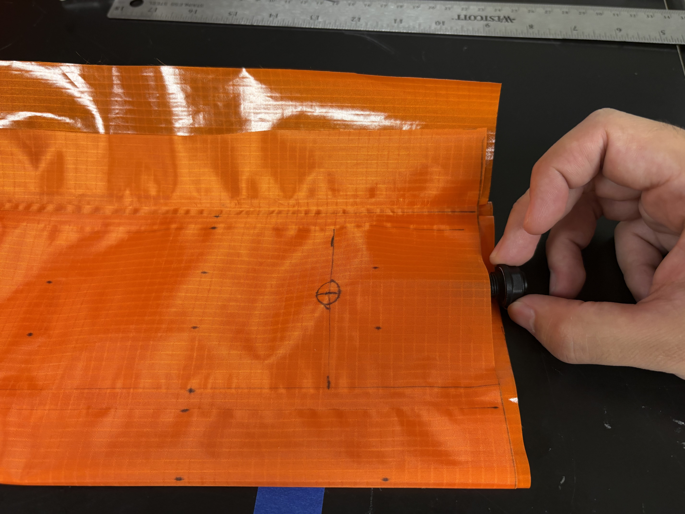
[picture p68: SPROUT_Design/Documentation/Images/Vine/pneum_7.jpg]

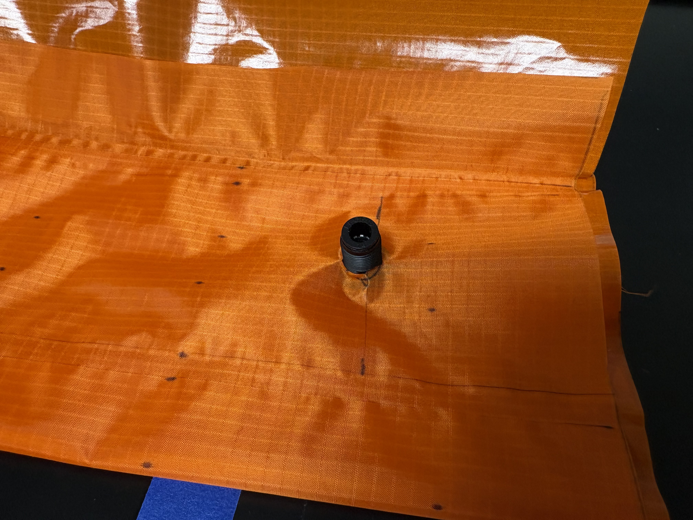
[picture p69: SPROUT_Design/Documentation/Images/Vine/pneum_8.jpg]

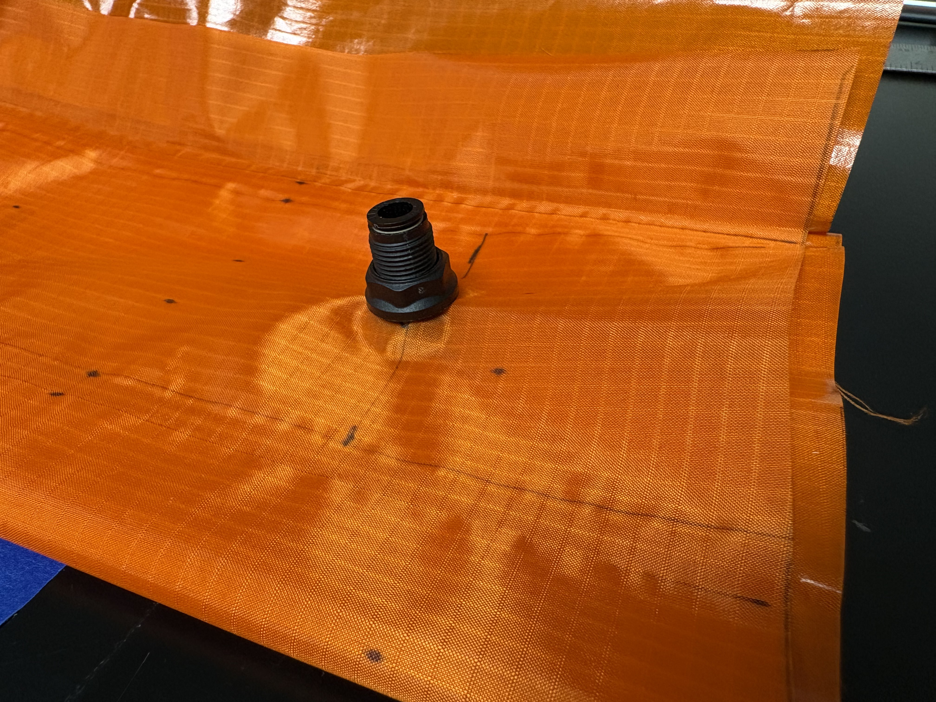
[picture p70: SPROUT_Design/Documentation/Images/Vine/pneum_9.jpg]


---

## Step 4: Inspection and validation

### Visual inspection

Verify:
- seam continuity
- fabric integrity
- pneumatic adapter attachment

### Leak / pressure test

To test the robot, use a compressed air line at low pressure (~2 psi) and verify that the main robot body holds pressure. Connect pressurized air to each pouch motor line to verify these are in working order as well.
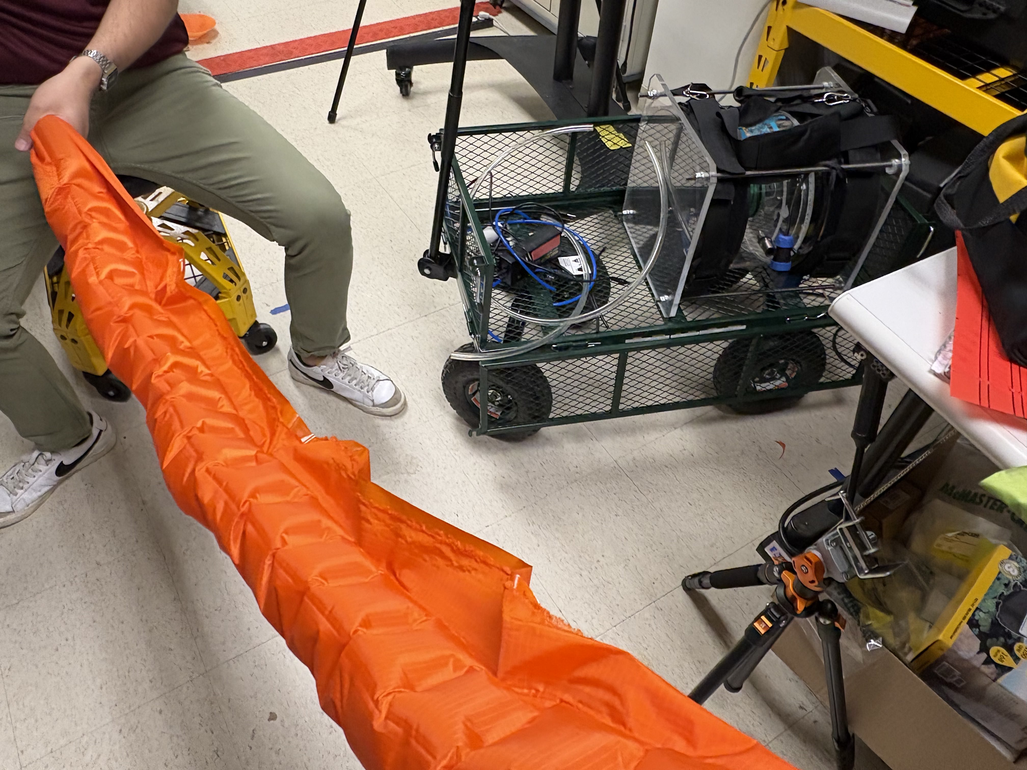
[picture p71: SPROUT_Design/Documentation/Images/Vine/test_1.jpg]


---

<!-- ## Integration with the base

TODO: How the finished vine mounts into the reel and connects to the base —
see [Assembly → Step 8]({{ site.baseurl }}/documentation/assembly.html#step-8-assembly-with-robot-base) for how the base itself goes together. -->

## Reference

The current base construction follows the steps from
[vinerobots.org](https://www.vinerobots.org/), with modifications noted in
[Assembly → Step 8]({{ site.baseurl }}/documentation/assembly.html#step-8-assembly-with-robot-base).

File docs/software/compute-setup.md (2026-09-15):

---
layout: default
title: Compute Setup
parent: Software
has_children: true
nav_order: 1
---

# SPROUT Compute
{: .no_toc }

Source: [`SPROUT_Design/Code/compute_setup`]({{ site.github_blob }}/SPROUT_Design/Code/compute_setup/README.md)
{: .label .label-green }

System Architecture

Reference system architecture for the fully realized system.

## Setup

Set up the [Jetson]({{ site.baseurl }}/software/jetson-bootstrap.html), then configure [USB device rules]({{ site.baseurl }}/software/usb-rules.html) for the controllers and Arduino.

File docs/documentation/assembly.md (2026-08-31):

---
layout: default
title: Compute Box
parent: Documentation
nav_order: 3
---

# Compute Box Assembly
{: .no_toc }

<style>
  .center-img {
    display: block;
    margin-left: auto;
    margin-right: auto;
    width: 50%;
  }
</style>

This page provides step-by-step instructions for assembling the SPROUT compute
box following [enclosure preparation]({{ site.baseurl }}/documentation/enclosure.html).

{: .important }
> Before beginning assembly, ensure that:
>
> - enclosure preparation is complete
> - all bonded components have fully cured
> - all hardware listed in the [BOM]({{ site.baseurl }}/documentation/bom.html) is available

## Table of contents
{: .no_toc .text-delta }

- TOC
{:toc}

---

## Assembly overview

Assembly proceeds in the following order:

1. Install electropneumatic hardware
2. Install power subsystem
3. Mount compute hardware
4. Set electrical connections
5. Install external elements
6. Mount communication interfaces
7. Screen installation
8. Assembly with robot base
9. Final inspection

---

## Step 1: Mount electropneumatic hardware

### Required components

| Item | Qty |
|---|---|
| QB3 Pressure Regulators | 4 |
| Solenoid Valve 3/2 NC | 1 |
| 1/4" Push-to-Connect OD x 1/4" NPT Thread Tee | 3 |
| 1/8" Push-to-Connect OD x 1/16" NPT Thread Tee | 3 |
| 1/4" Push-to-Connect OD x 1/4" NPT Thread Elbow | 2 |
| 1/8" Push-to-Connect OD x 1/16" NPT Thread Elbow | 1 |
| 1/4" Push-to-Connect OD x 1/4" NPT Thread Straight Connector | 1 |

### Procedure

1. Position the QB3s and solenoid valve in the mounting plate. Secure to plate with adequate hardware. Make sure to line up the elements so the output ports are facing towards the outside of the plate, as shown below.
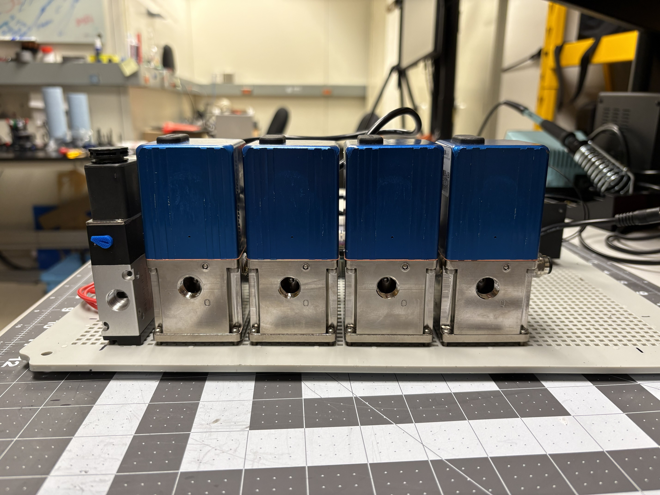
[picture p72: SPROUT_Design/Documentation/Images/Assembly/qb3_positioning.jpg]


2. Install the 1/4" Push-to-Connect OD x 1/4" NPT Thread Tee (3) and Elbows (2) in the electropneumatic components as shown. Plug in tubing to interconnect the elements pneumatic lines. These are the inlet ports of the pressure regulators.
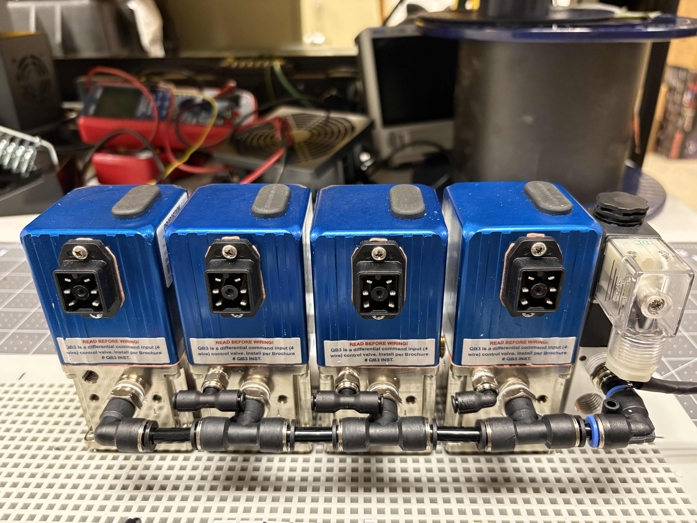
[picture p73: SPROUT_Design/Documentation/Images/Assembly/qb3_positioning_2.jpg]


3. Install the 1/16" Push-to-Connect OD x 1/8" NPT Thread Tee (3) and Elbows (2) in the electropneumatic components as shown. Plug in tubing to interconnect the elements pneumatic lines. These are the front exhaust ports of the pressure regulators.
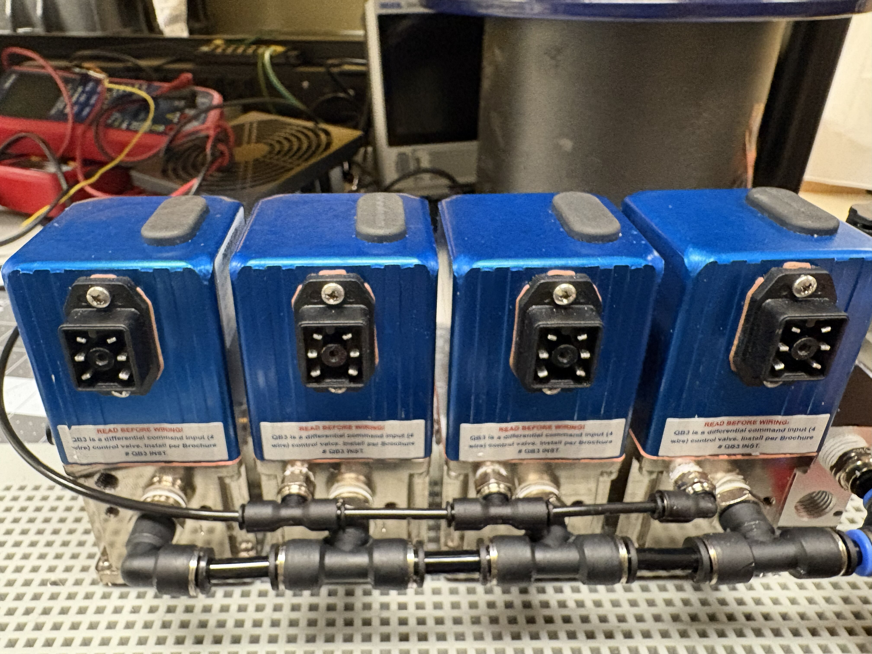
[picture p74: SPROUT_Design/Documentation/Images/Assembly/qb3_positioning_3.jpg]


4. Install a 1/4" Push-to-Connect OD x 1/4" NPT Thread Straight Connector in the last QB3 side exhaust port.
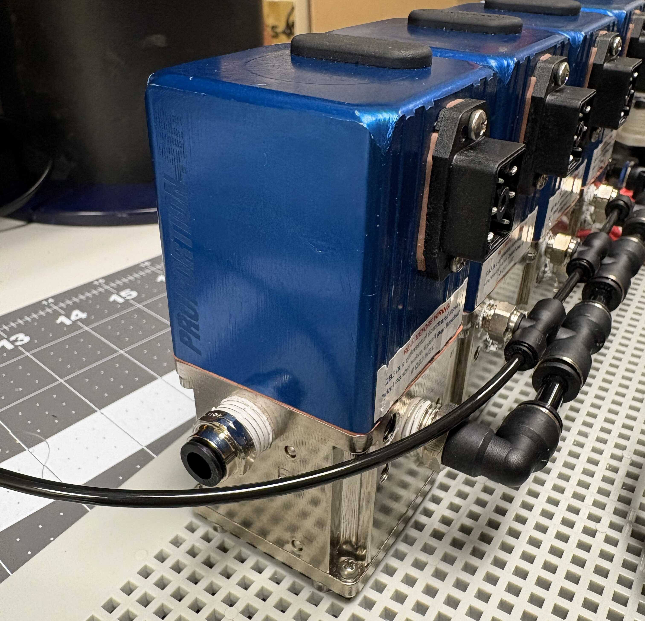
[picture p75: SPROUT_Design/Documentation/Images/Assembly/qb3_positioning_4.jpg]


5. Solder one end of 5 - 22 AWG stranded wires (~12 inches long each) to the QB3 connector's terminals. Cover wires with braided wire sleeving and insert two heat shrink tubing section of about an inch each. On the other end of the wire, crimp the ends and install on a 5-pin JST-HX connector. Follow the wiring diagram to have wires in the right order on the connector. Use a hot air gun to shrink the tubing. Repeat this process to make 4 connectors, like shown below.
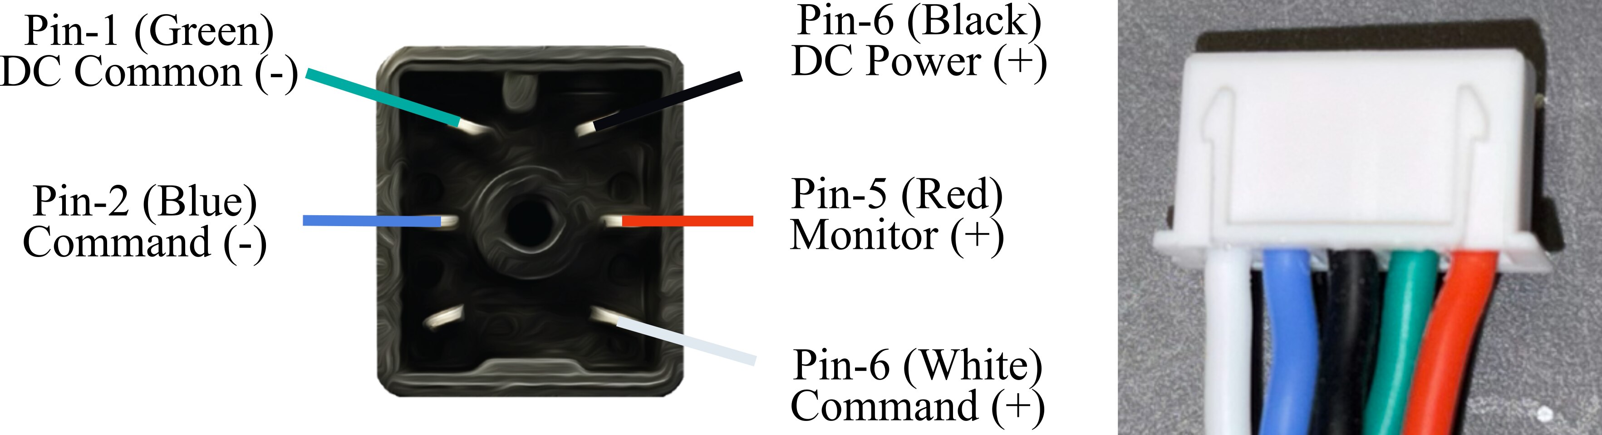
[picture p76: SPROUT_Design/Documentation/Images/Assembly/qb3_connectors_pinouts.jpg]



6. Solder one end of 2 - 22 AWG stranded wires (~12 inches long each) to the solenoid terminals (white to DC power +, black to DC power -). Cover wires with braided wire sleeving and insert two heat shrink tubing section of about an inch each. On the other end of the wire, crimp the ends and install on a 2-pin JST-HX connector. Follow the wiring diagram to have wires in the right order on the connector. Use a hot air gun to shrink the tubing.


---

## Step 2: Install power subsystem

### Required components

| Item | Qty |
|---|---|
| Battery Adapter | 1 |
| Cord gland | 1 |
| Buck Converters | 4 |
| Fuse Holders | 5 |

### Procedure

1. Mount the battery adapter to the external right side of the case. To do so, place the adapter flush against the top border (as shown below) and mark down the screw holes. Drill these out and install using appropriate fasteners.
2. The battery adapter usually comes with a fuse holder in line. Cut the wires to get rid of the fuse holder.
3. Drill a 1/2" hole next to the battery adapter, and install the cord gland. Pass the wires through it to the inside of the case, and tighten the gland.


4. Once inside, crimp the wires and install a 2.8mm 2-pin male connector. See below.


5. Crimp one end of an in-line fuse holder and a 16 AWG black wire (about 12" long) and install a 2.8mm 2-pin female connector. On the free end of the fuse holder, solder a 30" long 16 AWG red wire, and cover the solder with heat-shrink tubing.
6. Connect the 2.8mm connectors. Install a 20A fuse in the holder.


7. Cut about 30" of red 16 AWG wire. Along with the other 30" long red wire, cover them with braided wire sleeving and insert two heat shrink tubing section of about an inch each. Leave both ends of the new wire free for now.


8. Solder about 15" of 16 AWG wire to the INPUT end of each of 4 buck converters (red for POWER, black for GND). Solder another 15" of 16 AWG wire to the OUTPUT pins (red for POWER, black for GND).
9. Cut the output POWER wire (red) of each buck converter about 5" from the boards, and install an in-line fuse holder by soldering and applying heat-shrink tubing.
10. For one of the buck converters, cut both the PWR and GND wires a few inches after the in-line fuse holder, and solder them to the end wires of a 3-ft long DC barrel plug cable. Install a 3A fuse in the fuse holder. This will be the power cord for the screen.
11. For another buck converter, cut about 3" of the leftover PWR and GND wires, and solder them to the end wires of a 6" long DC barrel plug cable. Install a 3A fuse in the fuse holder. This will be the power cord for the Jetson Nano.
12. For two of the leftover converters, install 2-pin JST-HX male connectors in the free ends. Refer to the image for the wire order in the connector. Install 5A fuses in the fuse holders of these power lines.


13. Stack the buck converters using M3 standoff spacers, with the barrel plug one all the way to the top.
14. Connect all 4 input POWER wires from the buck converters to a 5-pin lever wire connector. Do the same for all 4 input GND wires. The end product should look as below.


15. Secure the stacked buck converters and lever connectors to the plate using fasteners. Use zip ties and adhesive tie mounts to hold wiring in place on the plate.

16. Up to this point, the mount plate should look similar to the image shown below. *(This picture does not show the 1/8" tubing connections between exhaust ports — make sure you have those in place; see Step 1.3.)*


17. Connect an 18V power supply to the lever connector and adjust all the buck converters output voltage to 15V. Disconnect power supply when done.


{: .warning }
> Double-check every buck converter output reads 15V *before* it is wired downstream. Compute and peripheral hardware connected to an over-voltage rail can be permanently damaged.

---

## Step 3: Install compute hardware

### Required components

| Item | Qty |
|---|---|
| NVIDIA Jetson Nano | 1 |
| Jetson 3D-printed housing | 1 |
| Arduino Uno Rev3 | 1 |
| Custom Arduino Shield PCB | 1 |
| DC Motor Driver | 1 |
| Buck Converters | 1 |
| Dual-Mode Wireless NIC Module | 1 |

### Procedure

1. Install wireless NIC module to Jetson. Connect the antenna cables. Mount the Jetson computer to the 3D-printed housing using appropriate fasteners. Mount assembly to plate.



2. Solder about 5" of 22 AWG stranded wire to the INPUT of a buck converter and install a JST-HX male connector. Solder about 2" of 22 AWG stranded wire to the OUTPUT of this buck converter, and install a JST-HX female connector. Follow the image below to have wires in the right order on the connectors.



3. Mount the DC Motor Driver, Arduino Uno Rev3 with custom shield, and the buck converters from the previous step to the plate using adequate fasteners and standoffs.


---

## Step 4: Electrical connections

Continue with [Wiring → Section 1]({{ site.baseurl }}/documentation/wiring.html#section-1-mounting-plate-electrical-connections). Once complete, come back to do step 5.

---

## Step 5: Install external elements

### Required components

| Item | Qty |
|---|---|
| 1/4" Pipe Nipples, 3" Long | 5 |
| 1/4" Push-to-Connect OD x 1/4" NPT Female | 3 |
| 1/2" Push-to-Connect OD x 1/4" NPT Female | 1 |
| 1/4" NPT Female, Quick Connect Air Coupler | 1 |
| 6-pole Receptacle Connector | 1 |
| Wireless NIC Module Antennas | 2 |
| One-way valve, 1/4" NPT Female x 1/4" NPT Male | 1 |
| 1/4" Push-to-Connect OD x 1/4" NPT Male | 1 |
| Through-wall Connector, 1/4" Push-to-Connect OD x 1/4" NPT Female | 1 |
| 1/4" Push-to-Connect OD Wye | 1 |
| 1/4" OD to 1/8" OD Push-to-Connect Adapter | 1 |

### Procedure

1. Drill a 3/4" hole about 2" away from the cable gland next to the battery. Insert the 6-pole receptacle connector in the hole, and mark down the mounting hole positions. Drill them out.


2. Solder 4-22 AWG stranded wires (about 12" long each) and 2-22 AWG stranded wires (about 10" long each) to the receptacle connector. Follow the wiring shown below to have wires in the right order on the connectors. This is the connector used to connect the robot base motor and encoder to the arduino and motor driver. Depending on how these are wired in the robot base, you may need to switch the wiring on this receptacle.


3. Cover the 4 longer wires with braided wire sleeving and insert two heat shrink tubing section of about an inch each. On the free end of the wire, crimp the ends and install a 4-pin JST-HX male connector (see picture above and below). Cover the 2 shorter wires in the same way, but leave the ends free and tin them.


4. Mount the receptacle to the case using appropriate fasteners.



5. On the left side of the case (the one that is untouched at this point), drill two holes to mount the wifi antennas.


6. Print the hole pattern provided in the [CAD]({{ site.baseurl }}/cad/) section, and cut it with scissors as shown below. These cuts help with alignment inside the case. Tape the cutout to the case in the inner, longer side by the hinge.



7. Drill the holes using 1/2" hole saws. Adjust the size as needed with a deburring tool so that a 1/4" Pipe Nipple can pass through it.


8. Mark down a dot 1.5" from the bottom and 1" from the right edge (see below) to drill another (9/16") hole to the right of the holes cut in the previous step.


9. Once all holes have been drilled, install the mount plate in the case. Secure with fasteners.


10. Install the antennas by mounting the connectors in the holes and screwing the antennas in.



11. Apply teflon tape in the pipe nipples, and install the connectors/adapters on one side: 3 with 1/4" Push-to-Connect OD x 1/4" NPT Female, 1 with 1/2" Push-to-Connect OD x 1/4" NPT Female, and 1 with 1/4" NPT Female, Quick Connect Air Coupler.


12. Pass the pipe nipples through the holes from the outside. Screw them into the QB3 pressure regulators and solenoid following the order shown below.



13. Connect the one-way valve, the push-to-connect adapter, and the push-to-connect through-wall connector as shown below.


14. Install the assembled adapter in the bottom hole made in step 8.



15. Connect the exhaust lines of the QB3s using a 1/8" to 1/4" adapter and a Wye to the installed one-way adapter. This will be the exhaust line.


---

## Step 6: Install communication interfaces

### Required components

| Item | Qty |
|---|---|
| USB Connector Panel-Mount | 2 |
| USB 3.0 Cable 1ft Long, A-to-A, Male-to-Male | 2 |
| DisplayPort to HDMI Cable, 3ft Long | 1 |
| HDMI Connector Panel-Mount | 1 |
| RJ45 Connector Panel-Mount | 1 |
| Ethernet Extension Cable 1ft Female-to-Male | 1 |
| LCD1602 Display Module | 1 |
| Emergency Stop Switch | 1 |
| Push Button Switch | 1 |
| Push Button Cover | 1 |
| Right Angle USB A to USB B male connector | 1 |

### Procedure

1. Laser cut an 18x24 3mm acrylic sheet using the pattern provided in the [CAD]({{ site.baseurl }}/cad/) section. Rendering the logo is optional.


2. Install the side handles, peripheral connectors, push button (with cover), E-button, and LCD screen as shown. From left to right: LCD screen, HDMI connector, USB-A connector, USB-A connector, Ethernet RJ45 connector, push button with cover, E-button.


3. Grab the end of the wires created in Step 2.7 (coming from the battery adapter fuse holder). Identify the cable inside the sleeve that is coming from the fuse holder; connect to the screw-in terminal in the push button. Screw another 3" segment of 16 AWG red wire to the other push button terminal.

4. The E-button should come with 2.8mm female spade crimp connectors. Crimp one on the short wire connected to the push button in the previous step, and another on the long wire coming from the sleeve.




5. On the other end of the sleeve, there is a free end on a red wire, and a black wire coming from the battery connector and fuse holder (see Step 2.7). Connect these to the lever connector's last empty slot (see Step 2.14).


6. Connect the cable with Dupont connectors coming from the Jetson to the LCD screen.


7. Connect the USB 3.0, A-to-A, Male-to-Male cables (2) to the panel ports. Connect the Ethernet Extension Cable 1ft Female-to-Male as well.


8. Connect the Right Angle USB A to USB B male connector from the Arduino to the Jetson.


9. Connect the USB A and ethernet cables to the Jetson. Connect the DP-to-HDMI cable as well.


10. Rest the panel in position over the interface panel mounts. 3D-print the vents and slide them into the panel.



---

## Step 7: Screen installation

### Required components

| Item | Qty |
|---|---|
| 15" LCD Display | 1 |
| M5 Plastic-Head Thumb Screws | 8 |

### Procedure

1. Pass the HDMI cable and the power cable (from Step 2.10) around the mounting plate and behind the vents, as shown below. Connect these to the screen.


2. Using the thumb screws, mount the screen to the 3D-printed brackets.


3. After this, the peripherals panel can be fastened to the mounting brackets using thumb screws.


---

## Step 8: Assembly with robot base

The base shown in these steps was built using the [vinerobots.org](https://www.vinerobots.org/) base construction steps. A few modifications have been made, but the overall shape and functionality are identical to the one on the Vine Robots website.

List of changes:
- The reel has been modified to include heat-set inserts, so the acrylic plates can be fastened into the 3D-printed reel core instead of hot-glued.
- The reel core has been modified to feature a shallow concave groove designed to passively guide the tendon toward the center of the spool during winding.
- As a safety precaution, 1/2" thick acrylic plates are secured with threaded rods to the sides of the base. This ensures the rubber ends do not come off due to over-pressurization or faulty hose clamp installation.
- We added a shoulder strap and carrying handles to facilitate base carrying.



### Procedure

To finish the assembly, we will mount the compute box in the robot base.

1. Print a second set of the curved foot assembly and place them on the floor, and pass velcro or ratchet straps on the foot assembly orifices.


2. Sit the cylindrical robot body on top of these.


3. Then, place the compute box on top of the robot.


4. Tighten the straps to secure the compute box around the cylindrical robot body. Connect the compute box to the vine robot base using the 6-pin receptacle, then attach a battery.


5. Finally, install a vine in the reel. Connect the robot base to the pneumatic outputs. The 1/2" push-to-connect provides pressure to the main connector of the robot base; the 3x 1/4" push-to-connect fittings provide pressure to the robot body pouch motor lines. The quick-disconnect connector is the main pressurized air inlet, to be connected to a compressor or pressurized air tank.


6. Attach a joystick to the compute box, and the system assembly is complete!


See [Vine Construction]({{ site.baseurl }}/documentation/vine-construction.html) for building the vine itself.

---

## Step 9: Final inspection

Verify:

- all hardware is secured
- all connectors are fully seated
- all wiring is strain relieved
- no loose hardware remains
- the enclosure lid closes without interference

---

## Next steps

Proceed to [Software Setup]({{ site.baseurl }}/software/) to flash and configure the Jetson, then run through validation testing before field deployment.

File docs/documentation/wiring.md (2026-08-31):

---
layout: default
title: Wiring
parent: Documentation
nav_order: 4
---

# Wiring
{: .no_toc }

<style>
  .center-img {
    display: block;
    margin-left: auto;
    margin-right: auto;
    width: 50%;
  }
</style>

## Table of contents
{: .no_toc .text-delta }

- TOC
{:toc}

{: .warning }
> Disconnect all power sources before making or changing any connections described below.

---

## Section 1: Mounting plate electrical connections

1. Cut 2-22 AWG stranded wire segments (about 8" long each). On one end, install a 2-pin JST-HX male connector. Leave the other end bare. Cover wire with sleeve mesh and heat-shrink tubing.



2. Connect the **JST-HX male** port to **M_DRV_PWR** in the arduino shield. Connect the bare **white wire** to **B+** in motor driver board, and bare **black wire** to **B-**.


3. Cut 2-22 AWG stranded wire segments (about 6" long each). On one end, install a 2-pin JST-HX male connector. On the other end, install a 2-pin female Dupont connector.



4. Connect the **JST-HX male** port to **M_DRV_ARD** in the arduino shield. Connect the Dupont wires to the motor driver (**green** wire to **DIR1**, **blue** wire to **PWM1**).


5. Cut 1-22 AWG stranded wire segment (about 5"). On one end, install a 2-pin JST-HX male connector. On the other end, install a 1-pin female Dupont connector.



6. Connect the **JST-HX male** port to **M_5V** in the arduino shield. Connect the Dupont wire to the motor driver (**GND**).


7. Connect the **JST-HX male** port from the buck converter **INPUT** to **Solenoid** in the arduino shield.


8. Connect the **solenoid** wiring to the buck converter **OUTPUT**.


9. Connect one of the JST-HX terminated power cables from the 15V buck converters to M_15V in the arduino shield.


10. Connect the other 15V JST-HX terminated buck converter to R_15V in the arduino shield.


11. Connect the QB3 JST connectors to the Actuator 1, Actuator 2, Actuator 3, and Chamber ports in the arduino shield. In this case, Chamber is the leftmost QB3, followed by Actuator 3, Actuator 2, and Actuator 1.



12. Make a connector with 4-22 AWG stranded wires, with 4-pin female Dupont connectors on one end. Make sure to follow the wire order shown in the picture below for this connector. Install individual 1-pin Dupont female connectors on the other end.



13. Connect the individual wires as shown. **White** is **SCL**, **Blue** is **SCA**, **Red** is **5.0V**, **Black** is **GND**.


---

Return to [Assembly → Step 5]({{ site.baseurl }}/documentation/assembly.html#step-5-install-external-elements) to continue the build.

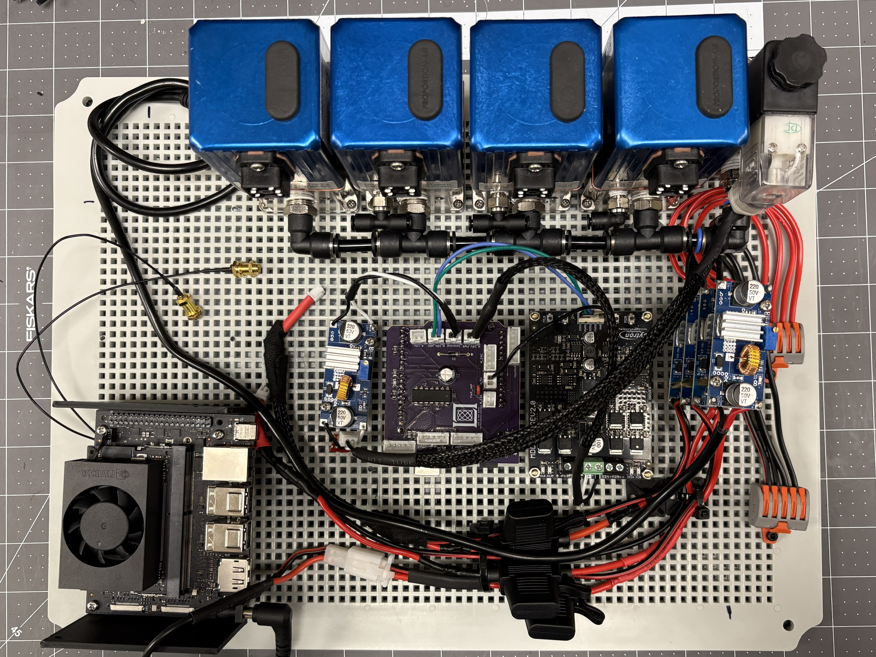
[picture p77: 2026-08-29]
SPROUT_Design/Documentation/Images/Wiring/plate_5.jpg

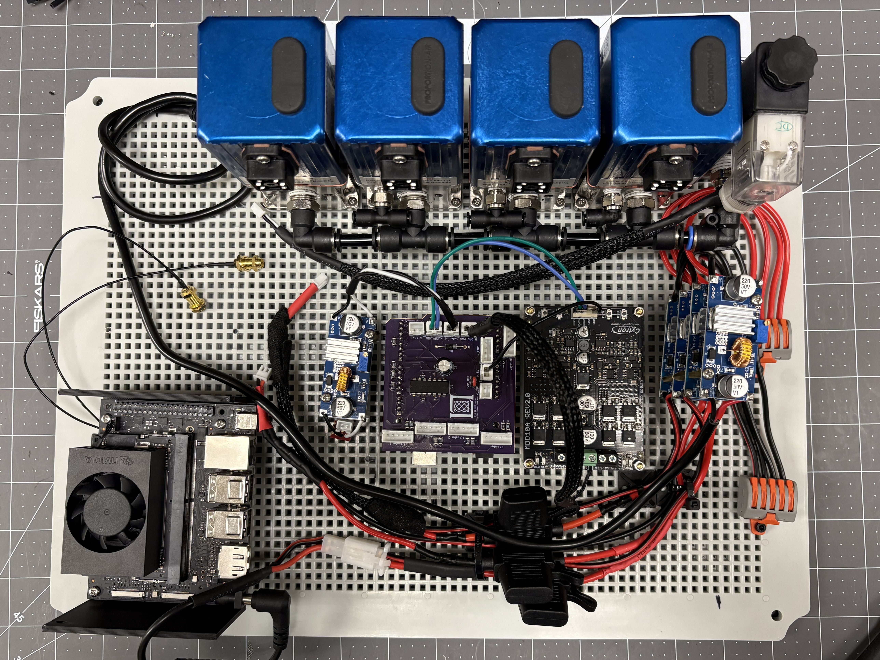
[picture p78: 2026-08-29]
SPROUT_Design/Documentation/Images/Wiring/plate_4.jpg

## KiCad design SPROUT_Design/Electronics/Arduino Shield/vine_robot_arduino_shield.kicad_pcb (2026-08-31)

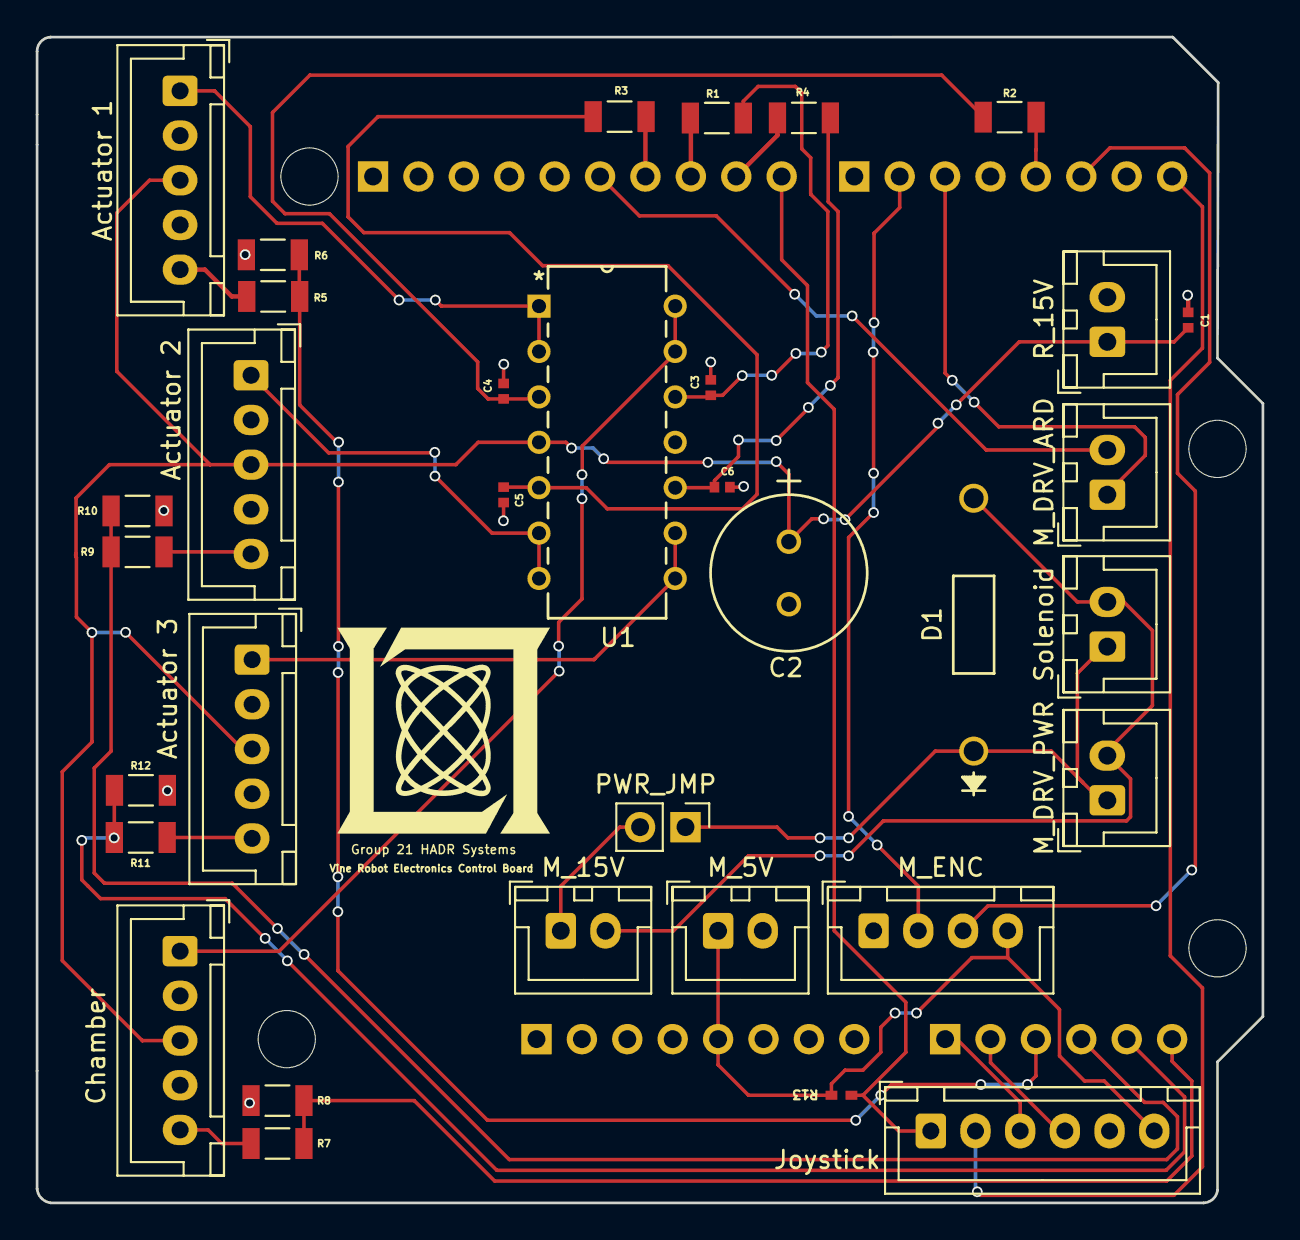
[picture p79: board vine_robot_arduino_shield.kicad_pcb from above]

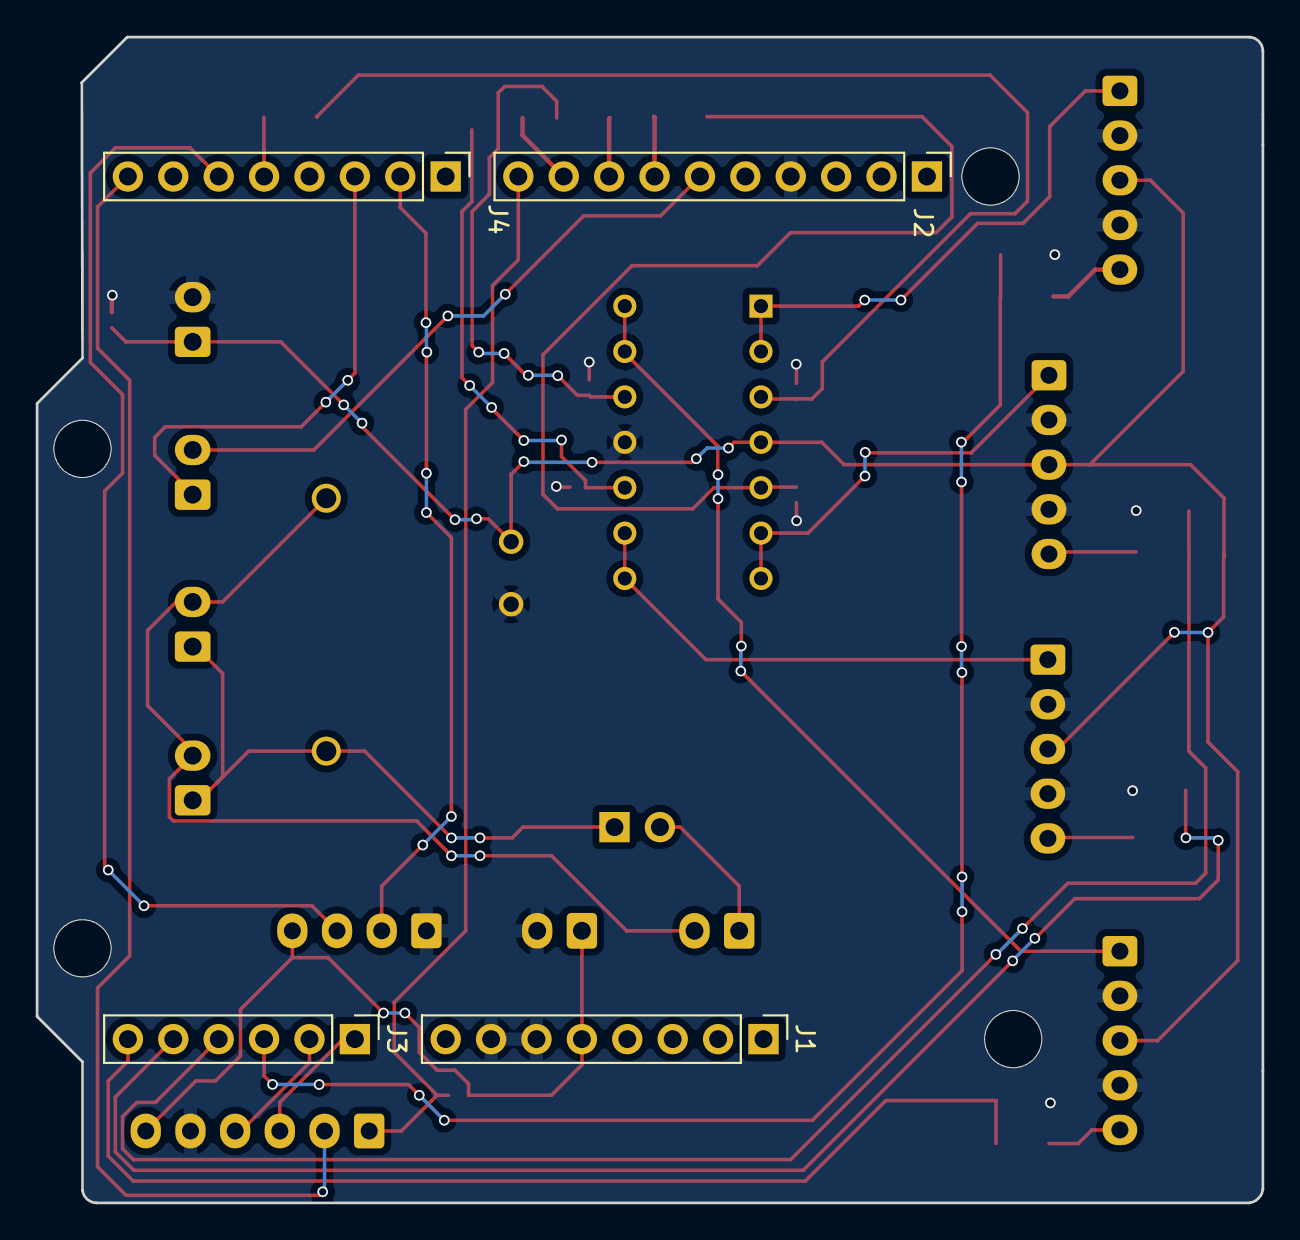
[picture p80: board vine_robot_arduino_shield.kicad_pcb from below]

Board: 2 copper layers, 68.6 x 65.2 mm, 42 parts (4 on the bottom side), 34 nets.

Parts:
Actuator 1: Reg1OutConn; JST_XH_B5B-XH-A_1x05_P2.50mm_Vertical
Actuator 2: Reg2OutConn; JST_XH_B5B-XH-A_1x05_P2.50mm_Vertical
Actuator 3: Reg3OutConn; JST_XH_B5B-XH-A_1x05_P2.50mm_Vertical
C1, C3, C4, C5, C6: 0.1µF; CAPC1005X55N
C2: 470µF; CAP_PK&slash_PZ_8X11P5_LOW_RUB
Chamber: RegChambOutConn; JST_XH_B5B-XH-A_1x05_P2.50mm_Vertical
D1: 1N4007; DIO_N4007-T_DIO
J1: Power; PinHeader_1x08_P2.54mm_Vertical
J2: Digital/PWM; PinHeader_1x10_P2.54mm_Vertical
J3: Analog; PinHeader_1x06_P2.54mm_Vertical
J4: Digital/PWM; PinHeader_1x08_P2.54mm_Vertical
Joystick: JoystickConn; JST_XH_B6B-XH-A_1x06_P2.50mm_Vertical
MH1, MH2, MH3, MH4: MountingHole_3.2mm
M_5V: MotorM5V; JST_XH_B2B-XH-A_1x02_P2.50mm_Vertical
M_15V: M15Vin; JST_XH_B2B-XH-A_1x02_P2.50mm_Vertical
M_DRV_ARD: MotorDrvConn; JST_XH_B2B-XH-A_1x02_P2.50mm_Vertical
M_DRV_PWR: MotorDrvPWR; JST_XH_B2B-XH-A_1x02_P2.50mm_Vertical
M_ENC: MotorEncConn; JST_XH_B4B-XH-A_1x04_P2.50mm_Vertical
PWR_JMP: PwrJmpr; PinHeader_1x02_P2.54mm_Vertical
R1, R2, R3, R4: 220kΩ; RESC3116X65N
R5, R6, R7, R8, R9, R10, R11, R12: 10kΩ; RESC3116X65N
R13: 1kΩ; RC0402N_YAG
R_15V: R15Vin; JST_XH_B2B-XH-A_1x02_P2.50mm_Vertical
Solenoid: SolenoidConn; JST_XH_B2B-XH-A_1x02_P2.50mm_Vertical
U1: LM324N; N14

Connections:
+5V: J1.5, Joystick.6, M_5V.1, M_ENC.4, R13.2
+15V: Actuator 1.3, Actuator 2.3, Actuator 3.3, C1.1, C2.1, Chamber.3, R_15V.1, U1.4 (VCC)
/2: J4.6, M_ENC.3
/8: J2.10, Joystick.1, R13.1
/12: J2.6, M_DRV_ARD.2
/*3: J4.5, R2.1
/*5: J4.3, M_DRV_ARD.1
/*6: J4.2, M_ENC.2
/*9: J2.9, R4.1
/*10: J2.8, R1.1
/*11: J2.7, R3.1
/ChambSigIn: C3.1, R1.2, U1.12 (4IN+)
/JoyAnalog1: J3.1, Joystick.3
/JoyAnalog2: J3.2, Joystick.4
/JoyDigi2: J4.8, Joystick.2
/Reg1MonIn: Actuator 1.5, R5.1
/Reg1MonOut: J3.3, R5.2, R6.1
/Reg1Out: Actuator 1.1, U1.1 (1OUT), U1.2 (1IN-)
/Reg1SigIn: C4.1, R2.2, U1.3 (1IN+)
/Reg2MonIn: Actuator 2.5, R9.1
/Reg2MonOut: J3.4, R9.2, R10.1
/Reg2Out: Actuator 2.1, U1.6 (2IN-), U1.7 (2OUT)
/Reg2SigIn: C5.1, R3.2, U1.5 (2IN+)
/Reg3MonIn: Actuator 3.5, R11.1
/Reg3MonOut: J3.5, R11.2, R12.1
/Reg3Out: Actuator 3.1, U1.8 (3OUT), U1.9 (3IN-)
/Reg3SigIn: C6.1, R4.2, U1.10 (3IN+)
/RegChambMonIn: Chamber.5, R7.1
/RegChambMonOut: J3.6, R7.2, R8.1
/RegChambOut: Chamber.1, U1.13 (4IN-), U1.14 (4OUT)
GND: Actuator 1.2, Actuator 1.4, Actuator 2.2, Actuator 2.4, Actuator 3.2, Actuator 3.4, C1.2, C2.2, C3.2, C4.2, C5.2, C6.2, Chamber.2, Chamber.4, J1.6, J1.7, J2.4, Joystick.5, M_5V.2, M_ENC.1, R6.2, R8.2, R10.2, R12.2, R_15V.2, U1.11 (GND)
unnamed: D1.1, M_DRV_PWR.1, PWR_JMP.1, Solenoid.1
unnamed: M_15V.1, PWR_JMP.2
unnamed: D1.2, M_15V.2, M_DRV_PWR.2, Solenoid.2

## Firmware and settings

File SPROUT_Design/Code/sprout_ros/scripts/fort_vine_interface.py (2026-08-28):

#!/usr/bin/env python3

import rclpy
import threading
import time
from rclpy.node import Node
from sensor_msgs.msg import Joy
from std_msgs.msg import String
from sprout_ros.msg import State
from sprout_ros.srv import PressureSet
import serial
import serial.serialutil


# Vine Robot Driver
# Author: Nathaniel Hanson
# ROS 2 Version

class VineDriver(Node):
    def __init__(self):
        super().__init__('vine_driver')
        self.serial_lock = threading.Lock()
        self.serial_port = '/dev/com/vine_arduino'
        self.baudrate = 115200
        self.ser = None
        self.serial_thread = threading.Thread(target=self._establish_serial_connection)
        self.serial_thread.daemon = True
        self.serial_thread.start()
        self.last_time = 0.0
        self.throttle_rate = 0.1  # seconds between messages (10 Hz)
        self.chamber_pressure = 2.5
        self.actuator_pressure = 2.5
        self.state_pub = self.create_publisher(State, '/vine_state', 1)
        self.joy_sub = self.create_subscription(Joy, '/joy', self.process_commands, 2)
        self.create_timer(0.01, self.read_serial)
        self.srv = self.create_service(
            PressureSet,
            '/pressure_set',
            self.handle_pressure_request,
        )

    def handle_pressure_request(self, request, response):
            """
            Handle request to update the maximum chamber and actuator pressures. 
            This is triggered by changes to the values on the joystick nodes
            """
            try:
                self.chamber_pressure = request.chamber_val
                self.actuator_pressure = request.actuator_val
                response.success = True

            except Exception as e:
                response.success = False
                response.message = str(e)
                self.get_logger().error(str(e))

            return response

    def _establish_serial_connection(self):
        delay = 1
        while rclpy.ok():
            try:
                self.get_logger().info(f'Trying to connect to {self.serial_port}...')
                self.ser = serial.Serial(
                    self.serial_port,
                    self.baudrate,
                    timeout=0.5,
                )
                self.get_logger().info('Serial connection established')
                return
            except serial.serialutil.SerialException as e:
                self.get_logger().warn(f"Serial connection failed: {e}")
                time.sleep(delay)
                delay = min(delay * 2, 30)  # exponential backoff, max 30 sec

    def process_commands(self, msg: Joy) -> None:
        '''
        Map commands to a compact string and send over serial.
        '''
        if not self.ser or not self.ser.is_open:
            self.get_logger().warn("Serial port not available. Skipping command.")
            return
        now = time.time()
        if now - self.last_time >= self.throttle_rate:
            self.last_time = now
            to_send = f"SET,{msg.buttons[7]},{msg.buttons[2]},{msg.buttons[0]},{msg.buttons[6]},{msg.buttons[4]},{msg.buttons[1]},{msg.buttons[5]},{msg.axes[4]},{msg.axes[3]},{self.chamber_pressure},{self.actuator_pressure}"
            self.get_logger().info(f"SENDING: {to_send}")
        else:
            return
        # int rb         = (int)values[0]; pouch pressure reset
        # int dpad_down  = (int)values[1]; motor speed decrease
        # int dpad_up    = (int)values[2]; motor speed increase
        # int triangle   = (int)values[3]; increase p
        # int x          = (int)values[4]; decrease p
        # int square     = (int)values[5]; motor stop
        # int circle     = (int)values[6]; empty
        # float y_joy    = values[7] * 5.0;         // Amplify for actuator control
        # float x_joy    = values[8] * 5.0 * -1.0;  // Inverted for consistency
        try:
            with self.serial_lock:
                self.ser.write((to_send + '\n').encode())
        except Exception as e:
            self.get_logger().warn(f"Serial write error: {e}")
            self._restart_serial_connection()

    def read_serial(self):
        if not self.ser or not self.ser.is_open:
            return

        try:
            with self.serial_lock:
                line = self.ser.readline().decode(errors='ignore').strip()

            if not line:
                return  # Skip empty lines

            self.get_logger().debug(f"Received: {line}")

            if line.startswith("STATE"):
                # parts = line.split(",")[1:]  # skip 'STATE'
                parts = [float(z.strip()) for z in line.split(",")[1:]]
                if len(parts) != 12:
                    self.get_logger().warn(f"Unexpected STATE format: {line}")
                    return

                msg = State()
                msg.cp_a = float(parts[0])
                msg.cp_s = float(parts[1])
                msg.a1_a = float(parts[2])
                msg.a1_s = float(parts[3])
                msg.a2_a = float(parts[4])
                msg.a2_s = float(parts[5])
                msg.a3_a = float(parts[6])
                msg.a3_s = float(parts[7])
                msg.d_s = float(parts[8])
                msg.d_c = float(parts[9])
                msg.c_m = float(parts[10])
                msg.a_m = float(parts[11])
                self.state_pub.publish(msg)
            else:
                self.get_logger().warn(f"Invalid vine state received: {line}")

        except Exception as e:
            self.get_logger().warn(f"Serial read error: {e}")
            self._restart_serial_connection()

    def _restart_serial_connection(self):
        try:
            if self.ser:
                self.ser.close()
        except Exception:
            pass
        self.ser = None
        self.serial_thread = threading.Thread(target=self._establish_serial_connection)
        self.serial_thread.daemon = True
        self.serial_thread.start()


def main(args=None):
    rclpy.init(args=args)
    node = VineDriver()
    try:
        rclpy.spin(node)
    except KeyboardInterrupt:
        pass
    finally:
        node.get_logger().info('Shutting down VineDriver node')
        if node.ser and node.ser.is_open:
            node.ser.close()
        node.destroy_node()
        rclpy.shutdown()


if __name__ == '__main__':
    main()

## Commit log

2026-08-28 adds assembly images
2026-08-29 adds wiring images
2026-08-29 adds Enclosure photos
2026-08-29 adds sprout base cad
    [1860N13_Wet-Location HDMI Connector.SLDPRT, 3216K56_Harsh Environment Mini Signal Power Connector.SLDPRT, 5697T29_Wet-Location Data Connector.SLDPRT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]
2026-08-31 adds CAD
    [1314-0016-0250 assembly.STEP, 1568A64_Threaded-Hole Round Pull Handle.SLDPRT, 1860N13_Wet-Location HDMI Connector.SLDPRT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]
2026-08-31 updates documentation
    [bom_draft.xlsx]
2026-08-31 add revised arduino and electornics
    [vine_robot_arduino_shield-B_Cu.gbl, vine_robot_arduino_shield-B_Mask.gbs, vine_robot_arduino_shield-B_Paste.gbp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]
2026-09-04 Fix broken links/images, clean up stale references, rename vine_control_mitll -> vine_control
    [vine_control_uno.ino]
2026-09-15 refactors to add STEP files
    [1314-0016-0250 assembly.STEP, 1314-0016-0250 assembly.STEP.STEP, 1314-0016-0250.STEP.STEP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]
2026-09-15 updates documentation with new images
    [bom_draft.xlsx]
2026-09-15 adds working solidworks model
    [SPROUT_assembly_exterior.stl]
